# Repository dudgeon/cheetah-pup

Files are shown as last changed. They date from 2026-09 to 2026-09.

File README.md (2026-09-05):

# Cheetah Pup

An experimental, hobbyist-scale quadruped robot for reinforcement-learning research:
Mini-Cheetah-style 12-DOF body geometry and leg kinematics, built with Feetech
STS3215-class smart servos and much of the surrounding stack (power, sensors, training
approach) drawn from Hugging Face/Pollen Robotics' open-source **Open Duck Mini v2**
project.

**Status**: Phase 1 complete, Phase 2 CAD first pass done. The design is locked (candidate A ·
direct drive, size M — see [`docs/design/01-candidates.md`](docs/design/01-candidates.md) and
`docs/design/locked.json`), the MuJoCo model is validated
([`docs/design/02-sim-validation.md`](docs/design/02-sim-validation.md)), the RL environment is
built and smoke-tested ([`docs/design/03-rl-environment.md`](docs/design/03-rl-environment.md)),
and the build123d CAD of every printed part now feeds the simulator its masses, inertias and
meshes ([`docs/design/04-cad-detail.md`](docs/design/04-cad-detail.md)). Next: confirm the servo
interface on a real STS3215, the first cloud-GPU training run, and the second CAD pass.

**Start here**: [`docs/HANDOFF.md`](docs/HANDOFF.md) is the project plan — decisions made and
why, architecture, phased build sequence, budget, safety, and open questions.
[`docs/DESIGN_LOG.md`](docs/DESIGN_LOG.md) is the dated record of decisions and milestones.
[`docs/research-appendix.md`](docs/research-appendix.md) is the research backing the decisions.

## Repo layout

```
cheetah_pup/            Design library (SI units): servo + electronics data, parameters and
                        presets (incl. the locked design), 3-DOF leg kinematics, gait generation,
                        sizing analysis, MJCF generation, MuJoCo validation, page builders
cheetah_pup/rl/         MuJoCo Playground (MJX) environment, domain randomization, PPO runner
cad/                    build123d CAD: STS3215 model and interface conventions, printed parts in
                        their MuJoCo body frames, assembly + mass properties + STEP/STL export
cad/exports/            Generated: step/ and stl/ per part, mass_properties.json (read by the
                        MJCF generator), viewer_meshes.json (read by the DR-04 page builder)
sim/                    Generated models (cheetah_pup.xml, cheetah_pup_rl.xml) and validation
                        recordings; checkpoints are written to sim/checkpoints (ignored)
tests/                  pytest suite (design library, MJCF, RL environment)
docs/                   Plan, design log, research; docs/design/ holds each design review
docs/design/review/     DR-01 candidate review page (template + build)
docs/design/replay/     DR-02 sim playback page (template + build)
docs/design/cad/        DR-04 CAD review page with a WebGL viewer (template + build)
vendor/                 Git submodules: external reference repos (see vendor/README.md)
```

PCB design and firmware directories will be added as those build phases start (see
`docs/HANDOFF.md` §5).

## Working with the code

```
python -m venv .venv && .venv/bin/pip install -e ".[sim,rl,dev]"
.venv/bin/pytest tests/test_kinematics.py tests/test_analysis.py tests/test_mjcf.py   # fast
JAX_PLATFORMS=cpu .venv/bin/pytest tests/test_rl_env.py                               # ~2 min JIT
.venv/bin/python -m cheetah_pup.mjcf sim/cheetah_pup.xml            # model from the locked design
.venv/bin/python -m cheetah_pup.mjcf sim/cheetah_pup_rl.xml --rl    # training variant
.venv/bin/python -m cheetah_pup.validate sim/cheetah_pup.xml        # stand + gait recordings
.venv/bin/python -m cheetah_pup.build_replay                        # rebuild the DR-02 page
.venv/bin/python -m cheetah_pup.build_artifact                      # rebuild the DR-01 page
JAX_PLATFORMS=cpu .venv/bin/python -m cheetah_pup.rl.train --smoke  # PPO pipeline check
```

The CAD needs the `cad` extra (build123d pulls in OCP, so use a separate venv if the sim one
is precious):

```
python -m venv .venv-cad && .venv-cad/bin/pip install -e ".[cad]"
.venv-cad/bin/python -m cad.assembly                 # STEP/STL, mass_properties.json, viewer meshes
.venv/bin/python -m cheetah_pup.mjcf sim/cheetah_pup.xml && .venv/bin/python -m cheetah_pup.mjcf sim/cheetah_pup_rl.xml --rl
.venv/bin/python -m cheetah_pup.build_cad_review     # rebuild the DR-04 page
```

`python -m cheetah_pup.mjcf` uses the CAD inertias and meshes whenever `cad/exports` matches the
locked design; `--no-cad` writes the Phase 1 primitive model instead.

`cheetah_pup.design.PRESETS` holds the candidates; `cheetah_pup.analysis.metrics()` sizes any
`DesignParams`. The review page's JavaScript mirrors the same math and cross-checks itself
against the package's numbers at load.

## Getting the code

This repo uses git submodules for vendored reference material:

```
git clone --recurse-submodules <this-repo-url>
# or, if already cloned:
git submodule update --init --recursive
```

## License

This repo's own code is MIT licensed (see `LICENSE`) unless noted otherwise. Vendored
reference material under `vendor/` keeps its own upstream license — see
`vendor/README.md` for exact terms per repo, including a few that are reference-only
pending license clarification from their authors.

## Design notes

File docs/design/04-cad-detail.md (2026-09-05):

# DR-04 — CAD detail of the locked design (Phase 2, first pass)

**Review page**: DR-04 · CAD detail — https://claude.ai/code/artifact/6b9c8170-cae2-4a28-a494-7ba0548bcc4b (WebGL viewer with
gait playback and a joint sweep, part and body tables, hardware checklist). Rebuild with
`python -m cheetah_pup.build_cad_review` after `python -m cad.assembly`.

**Files**: `cad/` (build123d model), `cad/exports/step/*.step` (per part plus
`assembly_nominal_stance.step` and the servo), `cad/exports/stl/*.stl` (millimetres, each part in
its MuJoCo body frame), `cad/exports/mass_properties.json` (per-part and per-body mass, centre of
mass, inertia; servo and electronics placements), `cad/exports/viewer_meshes.json` (viewer data).

## What was built

A parametric build123d model of the locked design, `cheetah_pup.design.locked()`, with every
printed part modelled in the frame of the MuJoCo body that carries it, so the STL files drop into
the simulator without transforms and the per-body mass properties are the simulator's `<inertial>`
elements. The servo is modelled from Open Duck Mini v2's STS3215 case meshes (`cad/servo.py`).

| Part | Qty | Class · effective solid | Each | Purpose |
|---|---|---|---|---|
| Trunk tub | 1 | shell · 95 % | 169.0 g, 143.5 cm³ | Floor, walls to the split, abad servo cradles (windowed shelves, ribs), end-wall bores and M2 holes, battery rails, Pi standoffs, lid bosses |
| Trunk lid | 1 | shell · 95 % | 72.8 g | Split to the top, vent slots, lid screws, PCB bosses hanging from the underside |
| Abad bracket | 4 (each a distinct mirror) | plate · 85 % | 13.6 g | Bolts to the abad horn; carries the hip servo with its horn at the thigh plane (back plate, bar, servo plate with Ø21 bore, gusset) |
| Thigh | 4 (2 L, 2 R) | plate · 85 % | 24.5 g | 3.5 mm plate on the hip horn; knee servo cradle gear-end-down inboard of the plate; knee bore and mounting holes |
| Shank | 4 (2 L, 2 R) | beam · 75 % | 9.3 g | Pad on the knee horn disc; 14 mm-wide beam with a jog inboard so the foot lands 3.25 mm outboard of the knee plane |
| Foot | 4 | TPU · 100 % | 5.0 g | Ø20 sphere at the sim's contact point (placeholder shape) |

Printed total 451 g; robot total **1.391 kg** with 12 servos (660 g), battery (125 g), Pi 5
(65 g), PCB + IMU (30 g), and 60 g of wiring — 1.6 % under the parametric estimate the sizing
used (1.413 kg).

## Servo interface convention (from the measured case)

- Frame: origin on the shaft axis at the horn-seat plane; L along the case (+35.1 to −10.1 mm),
  W ±12.36, A along the shaft (+A toward the horn; case bottom at −32.6).
- Fixed part: a 3 mm plate on the top-face step (A ∈ [1.1, 4.1]), four M2 screws (Ø2.4 clearance)
  into the tapped holes at (L, W) = (8.3, ±10.25) and (29.0, ±10.25); a Ø21 bore in which the
  Ø20 horn disc (A ∈ [2.1, 5.05]) rides as a plain bearing, 0.95 mm proud of the plate.
- Moving part: bolts to the horn's four Ø2.5 holes on r = 7 plus the Ø3.2 centre, seating on the
  proud disc face.
- Pockets: 0.4 mm clearance around the case, including the Ø20 × 2.1 idler disc on the bottom.

## Packaging refinements made while modelling (kinematics unchanged)

| Parameter | Phase 1 | Phase 2 | Why |
|---|---|---|---|
| `abad_link` | 40 mm | **43 mm** | Room for the hip servo case (24.7 wide) plus the bracket's servo plate between the abad axis and the thigh plane |
| `abad_to_abad` | 70 mm | **74 mm** | Abad servo cases (35.7 tall) side by side in the tub with the centre rib |
| `hip_x_offset` | 15 mm | **18 mm** | End wall (3) + step (1.1) + horn disc + bracket back plate before the hip axis |
| `foot_y_offset` | — | **3.25 mm** | The shank sits on the knee horn disc outboard of the thigh plate; the beam jogs back inboard but the foot ends 3.25 mm outboard |
| Layout | Pi 5 and PCB on a top layer, Pi transverse | **Battery on the floor, Pi 5 above it in the centre bay; PCB + IMU hung from the lid over the front abad servos** | The centre bay between the servo cradles is the only 60 mm-tall volume; the PCB fits the 26 mm above the servo tops |

Shell width follows from the servo bay: `shell_width = abad_to_abad + 2 × (10.1 + 0.9 + wall)`
= 102 mm; shell length stays 144 mm.

## In the simulator

`cheetah_pup/mjcf.py` now defaults to the CAD model for the locked design: explicit `<inertial>`
per body from `mass_properties.json`, the STL meshes as visuals (`meshdir` relative to the XML),
servos placed by the recorded frames, feet at `y = ±foot_y_offset`. Collision stays primitive:
foot spheres in both variants; a shell box and leg capsules (hidden geom group 3) in the full
model only. `--no-cad` still generates the Phase 1 primitive model for any preset.

Re-validation on the CAD model (`sim/validation/`, DR-02 rebuilt): stands with 0.9 mm sag and
0.76° droop, knee hold 0.249 N·m; open-loop walk and trot both survive 6 s (walk 0.024 m/s,
trot 0.069 m/s, pitch ≤ 10°); the RL environment's four CPU tests pass on the new model.

## Known gaps and hardware checks

The review page lists what to confirm before printing. In short: the servo hole patterns and
horn fastener size are measured from a mesh, not a datasheet; the Ø21 bore clearance must be
tuned to the printer; joints are single-sided on the horn; hip pitch is limited to about ±60° by
the knee-servo case against the tub corner; battery, Pi cooler, and PCB envelopes are assumptions;
no wire clips, foot sockets, or fork supports are modelled yet. The tub is 169 g against the
143 g parametric shell estimate — acceptable, more windows possible.

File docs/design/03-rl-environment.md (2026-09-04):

# DR-03 — RL environment for the locked design

**Status**: built and smoke-tested on CPU; ready for a cloud-GPU training run.
Code: `cheetah_pup/rl/` (`base.py`, `joystick.py`, `randomize.py`, `train.py`, `constants.py`).
Model: `sim/cheetah_pup_rl.xml` from `python -m cheetah_pup.mjcf sim/cheetah_pup_rl.xml --rl`.
Tests: `tests/test_rl_env.py`. Stack: MuJoCo Playground (MJX) + Brax PPO, the same lineage as
Open Duck Mini's training; the environment mirrors Playground's Go1 joystick task (Apache-2.0),
which is the same 12-DOF abad/hip/knee quadruped layout.

## Task

Track a body-frame velocity command (vx, vy, yaw rate) on flat ground at 50 Hz control,
2 ms physics. Commands: |vx| ≤ 0.25 m/s, |vy| ≤ 0.10 m/s, |yaw| ≤ 1.0 rad/s, resampled at random
intervals with a chance of zeroing each component (stand still is part of the task).

## What the policy sees and does

| | |
|---|---|
| Observation (policy, 49) | gyro (3), gravity direction in the IMU frame (3), command (3), joint positions − standing pose (12), joint velocities × 0.05 (12), last action (12), foot contacts (4) — only what the real robot measures (BNO055 + servo encoders + foot switches). Noise added to each. |
| Observation (critic) | the above plus accelerometer, base linear/angular velocity, joint state without noise, actuator forces, foot velocities, air times, trunk height |
| Action (12) | offsets from the standing pose, ×0.3 rad; motor targets are slew-limited to the STS3215 firmware cap (5.29 rad/s) and clipped to the joint ranges before reaching the PD servos |
| Termination | trunk up-vector z < 0.3 (~73° tilt) or NaN |
| Episode | 1000 steps (20 s) |

## Rewards (per step, scaled by dt)

Tracking: lin-vel `1.5·exp(−|Δv|²/0.02)`, ang-vel `0.75·exp(−Δω²/0.2)`. Posture: orientation
−5, vertical velocity −0.5, roll/pitch rate −0.05, pose −/+0.3 toward the standing pose, soft joint
limits −1, stand-still −0.5 when the command is zero, termination −1. Effort: torques −0.002,
energy −0.01, action rate −0.01 (all ~10× the Go1 coefficients — our torques are ~10× smaller).
Feet: air time +0.2 (swing ≥ 0.1 s), clearance −1 toward a 30 mm swing height, slip −0.1.

## Domain randomization (per environment)

Floor friction U(0.5, 1.0); joint Coulomb friction ×U(0.8, 1.2); armature ×U(0.9, 1.1); trunk CoM
±10 mm; every body mass ×U(0.9, 1.1) plus ±0.1 kg on the trunk; joint zero offsets ±0.03 rad;
servo kp ×U(0.85, 1.15); torque limit ×U(0.85, 1.05) (battery sag). Pushes are implemented but off
by default. Backlash and the servo's rate-limited internal target come with BAM's actuator model
in the next step.

## Model variant differences from `sim/cheetah_pup.xml`

Feet-only collisions (shell and legs do not collide — Playground's convention for training speed;
falls are caught by the tilt termination), pyramidal friction cone, contact sensors on each foot,
the IMU frame sensor set, and a `home` keyframe alias. Masses, geometry, and the servo model are
identical.

## Running it

```
# CPU pipeline check (a few thousand steps, small networks; ~10 min mostly JIT)
JAX_PLATFORMS=cpu .venv/bin/python -m cheetah_pup.rl.train --smoke

# GPU run (cloud): install jax[cuda12] and mujoco-warp, then
.venv/bin/python -m cheetah_pup.rl.train --impl warp --num-timesteps 100000000 --num-envs 4096
```

Playground's Go1 PPO hyperparameters are the starting point (policy 512-256-128, value the same,
observation normalization on). Expect a first walking policy within tens of millions of steps —
Microduck reports 1–2 hours on one GPU at 4096 environments for a comparable task.

## Smoke test result (CPU, 2026-09-04)

`--smoke`: 8 environments, 100-step episodes, 64-64 networks, 2,048 requested timesteps → 5,120
executed (Brax rounds up to whole batches), 133 s wall time of which nearly all is JIT compile.
Evaluation with the barely-trained policy: episode reward 0.78, average episode length 99.7 of
100 (the robot mostly stays upright for 2 s from the standing pose), every reward term finite and
of the expected sign (tracking +34.8/+20.0, pose +27.5, orientation −8.2, energy −16.2, torques
−3.4, action rate −6.5, feet air time +0.35). Checkpoint `sim/checkpoints/smoke_params` (87 KB)
saved with `brax.io.model`. This proves environment, randomization, PPO, evaluation, and
checkpointing run together; it says nothing about walking quality — that needs the GPU run.

One compatibility fix was needed: Brax 0.14.2 calls `jax.device_put_replicated`, removed in
JAX 0.10; `cheetah_pup/rl/compat.py` restores it with the documented replacement.

## Next steps

1. Cloud-GPU training run; evaluate with `sim/cheetah_pup.xml` (full collisions) and in the DR-02
   playback page (a policy-driven recording is one function away in `validate.py`).
2. Actuator realism: BAM's MuJoCo actuator (rate-limited target, extended friction, backlash).
3. ONNX export of the policy MLP for the Raspberry Pi runtime (Phase 4).

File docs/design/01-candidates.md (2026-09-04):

# DR-01 — Leg architecture & proportion candidates

**Status**: awaiting the owner's selection. Review page: https://claude.ai/code/artifact/6b9c92f0-98d5-4cf1-928c-98a28d699ba4
(source: `docs/design/review/template.html`, built by `python -m cheetah_pup.build_artifact`).
Date: 2026-09-04. Analysis code: `cheetah_pup/` (tests in `tests/`).

## What is being decided

All candidates share the Mini Cheetah kinematics fixed in `docs/HANDOFF.md` §3: four legs, each with
abduction/adduction (axis along x, through the hip-pitch axis), hip pitch, and knee pitch, serial 2R
leg, knees pointing backward by default. What differs is **where the knee servo lives and how it
drives the shank** — which changes mass distribution, hip width, build complexity, and how much the
sim has to model beyond the servo itself.

| | **A · Direct drive** | **B · Coaxial hip + belt knee** | **C · Coaxial hip + pushrod knee** |
|---|---|---|---|
| Knee servo location | at the knee, inside the thigh | at the hip, coaxial with the hip servo, outboard of the thigh | same as B |
| Knee transmission | none (horn drives the shank) | GT2 belt, 20T→25T (1.25:1) | printed 4-bar pushrod (~1.2:1 average) |
| Thigh | housing around a 55 g servo | slim printed link with a belt cavity | slim printed link |
| Overall width (size M) | **182 mm** | 253 mm | 253 mm |
| Mass (size M) | 1.41 kg | 1.46 kg | 1.45 kg |
| Knee servo, trot peak | 0.77 N·m (40 % of stall) | 0.65 N·m (34 %) | 0.67 N·m (35 %) |
| Abad / hip, trot peak | 0.52 / 0.31 N·m | 0.54 / 0.32 N·m | 0.53 / 0.32 N·m |
| Peak servo speed, 1.4 Hz trot | 76 % of cap | 94 % of cap | 91 % of cap |
| Electronics fit | yes | yes | yes |
| Sim-to-real modeling | servo only (BAM covers it) | servo + belt compliance/stretch | servo + variable ratio + pin play |

Baseline geometry (size M): thigh 90, shank 85, abad link 40, hips 180 apart (fore-aft), abad axes
70 apart, shell 148 × 62 mm, hip height 120 mm (nominal hip −45°, knee 93° — Mini Cheetah stands at
−46°/92°). Sizes S/L scale the legs by 0.85/1.15.

## Findings that shaped the candidates

1. **The STS3215's speed cap, not its torque, is the binding constraint.** BAM's identification puts
   the firmware's target-rate limit at 5.29 rad/s (≈50 rpm). A 1.4 Hz trot with a 60 mm step and
   25 mm swing needs ~4 rad/s at the knee in direct drive. Any knee reduction multiplies servo speed by
   the same ratio: 1.5:1 (the first belt guess) exceeded the cap; 1.25:1 sits at 94 %. Practical
   trot frequency with these servos is ~1.2–1.5 Hz, i.e. 0.15–0.2 m/s. This is the "confident walker,
   not sprinting cheetah" trade-off from the decision log, now with a number on it.
2. **Direct drive does not need a reduction.** Knee torque at the trot peak (two legs, 1.5× dynamic
   factor, foot swept over the step) is ~0.77 N·m against a 1.91 N·m stall — 40 %, inside the 60 %
   peak allowance, and 12 % when standing on four legs. The belt's torque margin is a nice-to-have
   bought with speed.
3. **The Raspberry Pi 5 mounts transversely.** The shell is ~93 mm wide inside (set by the abad
   servos), so the Pi's 85 mm side fits across the body and it occupies only 56 mm of length. That
   freed ~40 mm and is why the body can stay near Mini Cheetah's length ratio (2.0× thigh vs 1.82).
4. **Abad torque is the second-largest load** (~0.53 N·m at trot peak) because the foot stands
   ~40 mm outboard of the abad axis — the price of a 36 mm-long servo in the hip cluster. Keep the
   abad link as short as the hip servo allows; the slider exposes it.
5. **Coaxial hip clusters cost +70 mm of width.** Two 36 mm servos side by side on the hip axis with
   the thigh between them make B and C nearly as wide as they are long (253 vs 260 mm); A's hip servo
   tucks inboard of the thigh plane.
6. **Hip servo clearance**: with the hip-pitch servo case pointing up from the hip axis, the hip axis
   needs to sit ≥ 16 mm beyond the shell end wall (`hip_x_offset`), or the case collides with the
   body. Baseline set to 16 mm.

## Recommendation

**A · Direct drive.** It is the lowest-risk path to a working RL robot and the best fit for the
"reuse the Hugging Face stack" decision: Open Duck Mini's joints are directly servo-driven, so its BAM
actuator identification, backlash modeling, and sim-to-real pipeline apply without adding a
transmission model. Torque margin is adequate at size M and speed margin is the best of the three.
Its costs — a heavier lower thigh and higher leg inertia — are real but small at this scale (swing
accelerations need ~0.04 N·m at the hip).

**B** is the choice if the owner values the Mini Cheetah look and low leg inertia and accepts the
width, the belt hardware, and belt stretch in the sim. A 1:1 belt (20T→20T) keeps A's torque/speed
numbers while still moving the servo mass to the hip — the ratio slider on the review page shows
that trade directly. **C** is least favored: the linkage bounds the knee range (~100°) and its
variable ratio is the hardest of the three to mirror in simulation.

## How to review and record a decision

The review page draws all three candidates at one scale (1.5 px per mm in every view) with the
servos at their measured size, the electronics volumes in the body, and the legs animated through
stand/crouch, walk, trot, pace, bound (range-of-motion demo), and lateral sway. Sliders change the
proportions and gait; the sizing panels and the "Current proposal" summary update live. **Save
decision** stores the candidate, slider values, tags, and comments to the page's data store
(`feedback/current`, plus a `reviews` log); Claude reads it back with the artifact tools. If the
store is unavailable, **Copy summary** and paste it into chat.

## After selection

1. Add a `LOCKED` preset to `cheetah_pup/design.py` from the saved decision (`docs/design/locked.json`).
2. Generate the MJCF from it: primitive collision geometry, component masses, STS3215 actuator model
   from BAM's parameters (position actuator with the identified kp/velocity cap, friction, armature).
3. Validate standing and IK-driven gait playback in MuJoCo; then build the RL environment.

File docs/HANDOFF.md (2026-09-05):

# Cheetah Pup — Handoff Document

**Status** (2026-09-04): Phase 1 complete. Research done, architecture decided, design library
built and tested, DR-01 candidates reviewed, **design locked (A · M)**, MuJoCo model generated and
validated open-loop (DR-02), and the **RL environment built and smoke-tested on CPU (DR-03)**.
**Next: the first cloud-GPU training run**, then Phase 2 CAD in parallel.

## 0. Progress

| Phase | State | Where |
|---|---|---|
| 0 · Repo & tooling | done | this repo; `vendor/README.md` |
| 1 · Kinematic validation | **done** — design locked; sim model validated (DR-02, re-run on the CAD model 2026-09-05); RL environment built (DR-03) | `docs/design/locked.json`, `cheetah_pup/mjcf.py`, `sim/cheetah_pup.xml`, `docs/design/02-sim-validation.md`, `docs/design/03-rl-environment.md`, `cheetah_pup/rl/`; DR-01 review https://claude.ai/code/artifact/6b9c92f0-98d5-4cf1-928c-98a28d699ba4; DR-02 playback https://claude.ai/code/artifact/2db54b1d-2707-4034-895f-95bec2b86281 |
| 2 · Mechanical CAD | **first pass done** (2026-09-05) — build123d model of every printed part with the measured STS3215 interface, STEP/STL exported, per-body mass properties feeding the sim (DR-04). Next: confirm the servo hole patterns on a real servo, then foot sockets, wire routing, fork supports, and the owner's Fusion 360 pass | `cad/`, `cad/exports/`, `docs/design/04-cad-detail.md`; DR-04 CAD review https://claude.ai/code/artifact/6b9c8170-cae2-4a28-a494-7ba0548bcc4b |
| 3 · Electrical / PCB | not started; volumes and power rails fixed in the design library | `cheetah_pup/electronics.py` |
| 4 · Firmware | not started | — |
| 5 · RL training | environment ready (`cheetah_pup/rl/`) and passing on the CAD-derived model; first GPU run pending; BAM actuator model to add | `docs/design/03-rl-environment.md`, `vendor/bam` |
| 6 · Bring-up | not started | — |

Keep `docs/DESIGN_LOG.md` current: one dated entry per decision or milestone.

**Purpose of this document**: everything needed to pick up this project cold and start the
detailed spec-and-build phase, without re-deriving decisions already made or re-running research
already done. If you're Fable 5.1 (or any future session) starting fresh: read this document in
full before writing any code, then start at [§8 Immediate next steps](#8-immediate-next-steps).

---

## 1. Project vision

An experimental quadruped robot for reinforcement-learning research:

- **Body geometry and leg kinematics** based on MIT's Mini Cheetah — full 12-DOF topology
  (hip abduction/adduction + hip pitch + knee pitch, ×4 legs), serial 2R leg chain per the real
  robot (not a parallel/5-bar linkage).
- **Actuators and much of the surrounding stack** based on Hugging Face/Pollen Robotics'
  **Open Duck Mini v2** — Feetech STS3215-class serial-bus smart servos, similar power
  architecture, similar sensor stack, and a training approach descended from the same lineage
  (MuJoCo-based RL, with Microduck's newer BAM-based actuator-identification approach folded in).
- A **custom PCB** for motor-bus, power, and sensor breakout (Open Duck Mini itself uses only an
  off-the-shelf Waveshare adapter — there is no existing open custom board for this actuator
  class doing exactly what we need, which is genuinely new work, not just a port).
- Scaled for a **hobbyist build**: FDM-printed structure, outsourced PCB assembly, Raspberry-Pi-class
  compute, cloud-GPU training.

This deliberately does **not** replicate the real Mini Cheetah's actuator technology (custom
quasi-direct-drive BLDC + FOC motor control). See §3 for why, and what that trade-off costs us.

---

## 2. How to use this document

- **§3** is the decision log — what was decided, why, and what alternatives were rejected. Don't
  relitigate these without a good reason; if you find one, update this log rather than silently
  diverging.
- **§4–§7** is the actual plan: architecture, phased build sequence, BOM/budget, safety.
- **§8** is where to start.
- **§9** is what's deliberately left open for you to resolve, with pointers to how.
- Full research backing every claim below lives in `docs/research-appendix.md` — this document
  states conclusions; that one shows the work.
- Reference repos are vendored as git submodules under `vendor/` — see `vendor/README.md` for
  what's there, exact licenses, and usage rules (a few are reference-only pending license
  clarification — don't copy code from those verbatim).

---

## 3. Decision log

These were made through direct interview with the project owner (dudgeon) on 2026-09-04, after
the research pass. Each is a real trade-off, not an arbitrary choice — the "why" matters if you
ever need to revisit one.

| Decision | Chosen | Alternatives considered | Why |
|---|---|---|---|
| **Actuators** | Duck-style smart servos (Feetech STS3215-class, serial bus, position-controlled) | True QDD BLDC (MIT-Cheetah/Solo12-style); hybrid | Matches the literal ask ("same actuators as the HF duck project"), reuses the most existing hardware/software, and is dramatically more tractable for a hobbyist build — no custom FOC motor-controller firmware needed. **Trade-off, stated explicitly and accepted**: not backdrivable, not true torque control. This robot will be a confident, capable *walker*, not a bounding/jumping *runner*. If dynamic gaits become a real goal later, that's a distinct future initiative (see §9), not a retrofit. |
| **Leg DOF** | Full 12-DOF (ab/ad + hip + knee ×4), matching real Mini Cheetah | Simplified 8-DOF (Solo8-style, sagittal only) | Explicitly requested as most faithful to "MIT Cheetah kinematics"; enables turning in place and lateral push recovery that an 8-DOF design can't do well. Costs 4 more servo channels/wiring runs than the simpler option. |
| **Fabrication access** | 3D printer (FDM) at home; PCB assembly outsourced (JLCPCB/PCBWay-style) | Hand-soldering fine-pitch SMD | **PCB design must use assembly-service-friendly footprints** (no 01005/BGA-if-avoidable, standard connectors) since hand-soldering fine-pitch SMD is not a confirmed skill. Structure/legs are FDM-printable — matches nearly every reference project surveyed. |
| **Training compute** | Cloud GPU credits, macOS as the dev/orchestration machine; local GPU explicitly deferred | Local NVIDIA GPU now; CPU-only | Not compute-constrained for the training stack choice — both MuJoCo Playground and the GPU-hungrier mjlab are viable. A **low-priority backlog item** (see §9.5) tracks revisiting local/hybrid GPU augmentation if cloud spend gets high; NVIDIA's brand-new "PAIR" project (announced 2026-09-03) was checked and does **not** help here — it's LAN-only inference pooling, not cloud training offload. |
| **CAD toolchain** | Code-first: **build123d** (or CadQuery as fallback) for parametric geometry + hand-authored **MJCF** for the early kinematics validation | Onshape | **Onshape is confirmed unreachable from this sandbox** (network egress test returned 403 on the CONNECT tunnel — the environment's proxy blocks it, same pattern the research agents hit on most non-GitHub domains). Since the owner wants Claude/Fable operating end-to-end from a Claude Code cloud instance without needing GUI CAD access, and wants STEP files that import cleanly into **Fusion 360** for their own later refinement pass, a scriptable Python CAD library is the only toolchain that satisfies both constraints. **Verify current pip-installability of build123d at the start of Phase 2** — if it has issues, CadQuery is the established fallback; both export STEP. |
| **Milestone sequencing** | Validate kinematics/topology in a *primitive-geometry* MuJoCo sim **before** investing in real CAD or manufacturability | Design real CAD first | The owner's own framing, adopted as-is: "a relatively early milestone should be validating a simple version of the design and kinematics in the RL environment to see if the basic project will work... and we will later refine, think about manufacturability." This is Phase 1 below, and it deliberately needs no CAD-derived meshes — simple boxes/capsules are enough to test whether the topology, proportions, and torque budget are sound. |
| **Experience / division of labor** | Claude/Fable drives ~95% of CAD, 100% of PCB/firmware/RL design; owner has CAD/DFM experience (not advanced linkages) and will do manufacturability refinement in Fusion 360 later | — | Stated directly. Electronics, embedded firmware, and ML/RL were **not** selected as areas of existing hands-on experience — treat those as fully Claude/Fable-driven too, not just CAD. The plan below is written assuming heavy autonomous execution with clear checkpoints for physical assembly (the one thing that must be done by human hands) and design review. |
| **Budget** | $600–$1,500 (excluding the 3D printer already owned) | — | See §6 for a rough BOM sanity check against this. |
| **License / distribution intent** | Personal project, **likely to open-source publicly** | Pure personal use; commercial | Drives §9.2 (unlicensed-repo caveats) and the recommended MIT license on this repo's own code (added — see root `LICENSE`). Since we're not depending on Microduck's CC BY-SA-NC assets at all (different hardware base), that restriction doesn't currently constrain us — but don't pull anything from `pollen-robotics/microduck_rl`'s asset files later without re-checking. |
| **Servo data source** (Phase 1) | STS3215 geometry measured from Open Duck Mini v2's case meshes; electrical/friction model from BAM's identified 7.4 V parameters | datasheet values from memory | Measured meshes and an identified model beat a remembered datasheet; both are vendored (`vendor/open_duck_mini`, `vendor/bam`) and encoded in `cheetah_pup/servo.py`. Design margins use the *datasheet* stall (1.91 N·m), not BAM's more optimistic implied stall. |
| **Sizing design point** (Phase 1) | Trot at 1.4 Hz, 60 mm step, 25 mm swing; loads = ¼ weight standing (≤ 25 % of stall) and ½ weight × 1.5 dynamic at trot peak (≤ 60 % of stall) | 1.6 Hz trot | 1.6 Hz pushed the knee past the STS3215's 5.29 rad/s cap even in direct drive. The cap, not torque, limits gait speed with these servos — accepted as the walker trade-off. |
| **Electronics layout** (Phase 1) | Two layers: abad servos + battery low, Pi 5 (transverse) + PCB high | Pi lengthwise | Transverse Pi saves ~40 mm of body length and keeps hip-to-hip near Mini Cheetah's 1.82× thigh ratio (2.0×). |
| **Knee-drive architecture & size** (locked 2026-09-04) | **A · direct drive, size M**, knees back, baseline proportions and gait — `cheetah_pup.design.locked()`, `docs/design/locked.json` | B coaxial + belt; C coaxial + pushrod; sizes S/L | Owner accepted the DR-01 defaults. A is the lowest-risk path and the best fit for reusing Open Duck Mini's directly-driven-joint sim-to-real pipeline; 40 % of stall at trot peak, 76 % of the speed cap, narrowest hips. |
| **Sim actuator model** (Phase 1) | MuJoCo `general` PD from BAM's electrical model (kp 18.8 N·m/rad, kd 0.56 N·m·s/rad), clamped at the datasheet stall 1.91 N·m; joint armature 0.026 kg·m², Coulomb 0.05 N·m | BAM's implied 3.4 N·m stall; BAM's full stateful model | Conservative clamp for viability; `--bam` flag generates the optimistic variant. The RL environment should move to BAM's MuJoCo integration (rate-limited target, extended friction) for the real training runs. |
| **Servo interface convention** (Phase 2, 2026-09-05) | Fixed part = 3 mm plate on the STS3215's top-face step, 4 × M2 into the case's tapped holes; Ø20 horn disc rides in a Ø21 printed bore as a plain bearing; moving part bolts to the horn's r = 7 pattern. Single-sided joints | Fork (idler-side) support on every joint; metal bearings | Derived from the measured case geometry (`cad/servo.py`); the simplest joint that uses the servo's own horn as the bearing, as Open Duck does. Fork supports are drawn as an upgrade path in the thigh cradle if horn play shows up. **Hole positions and horn screw size must be confirmed on a real servo** (§9.10). |
| **Phase 2 packaging refinements** (2026-09-05) | abad link 43 mm (was 40), abad axes 74 apart (was 70), hip x-offset 18 (was 15), feet 3.25 mm outboard of the knee plane; battery on the floor, Pi 5 above it in the centre bay, PCB + IMU hung from the lid over the front abad servos; shell 144 × 102 × 62 | Keep Phase 1 numbers and squeeze the parts | Each change is the minimum the real servo cases and interfaces need; leg lengths, hip spacing, stance and gait are unchanged, so the DR-01 sizing still holds (re-validated in sim). `docs/design/04-cad-detail.md` has the table. |
| **Sim fidelity source** (2026-09-05) | `mjcf.py` defaults to the CAD for the locked design: explicit `<inertial>` per body from `cad/exports/mass_properties.json`, STL meshes as visuals, feet spheres (plus hidden shell box and leg capsules in the full model) for collision | Mesh convex hulls for collision; keep the primitive model | Primitive collisions keep the RL model fast and match Playground's quadruped scenes; the CAD gives the masses and inertias the policy actually needs to be right. `--no-cad` keeps the Phase 1 model for the unlocked presets. Total 1.391 kg vs the 1.413 kg parametric estimate. |

---

## 4. Architecture overview

### 4.1 Mechanical
12-DOF quadruped, Mini-Cheetah-proportioned (long body relative to leg length, legs tucked
under the body rather than sprawled like a hobby "SpotMicro"-style bot). Actuators mounted at
the hip where possible (co-axial stacking, like Mini Cheetah/Open Duck Mini) to keep leg swing
mass — and thus reflected inertia the servo has to fight — low, even though we're not chasing
true QDD dynamics. Final scale/mass to be derived from servo torque budget during Phase 1 (see
§5), not fixed in advance — expect something in the rough neighborhood of Open Duck Mini's
footprint (that robot closes the loop on "how big can a 7.4V STS3215-driven robot be"), adapted
for quadruped proportions.

### 4.2 Electrical
- **Servos**: 12–14× Feetech STS3215-class, 7.4V, on a shared serial bus (final servo count and
  whether any joints need a higher-torque variant depends on Phase 1 torque analysis).
- **Custom PCB** (the "motor and sensor breakout" from the original brief): distributes bus +
  power to per-leg connectors (4 runs, not one long daisy chain through everything — more
  robust, easier to service than the stock Waveshare adapter's single chain), regulates 2S
  Li-ion (~7.4V, matches servo voltage directly with no separate boost/buck needed for the
  servo rail) down to 5V for compute and 3.3V for sensors, breaks out I2C for the IMU and room
  for future sensors (ToF, foot contact), includes battery voltage/current sensing, a fuse +
  reverse-polarity protection, and a **software+hardware E-stop** (MOSFET-switched servo power
  rail, killable independently of the Pi) — see §7 Safety.
- **Power**: 2S 18650 Li-ion pack + 2S BMS, mirroring Open Duck Mini v2 exactly (their choice
  already validates this voltage matches STS3215 servos directly).
- **Compute**: Raspberry Pi 5 (more headroom than Open Duck Mini's Pi Zero 2W — Pupper v3 made
  the same call for similar reasons: room for a camera and future sensor/ML work without being
  compute-starved). Pi Zero 2W remains a fallback if size/weight pressure shows up in Phase 1/2.
- **Sensors**: Bosch BNO055 9-DOF IMU at minimum (matches Open Duck Mini's choice, and BAM
  already models this class of setup); camera and/or foot-contact sensing as stretch additions
  once core locomotion works.

### 4.3 Software / training
- **Phase 1 (kinematics validation)**: quickest-to-stand-up MuJoCo setup (plain MuJoCo or MuJoCo
  Playground) on a hand-authored primitive-geometry MJCF. Goal is a yes/no answer on topology
  and rough torque budget, not a polished policy.
- **Phase 5 (production training)**: given cloud GPU is available (not the hobbyist
  hardware-constrained case Playground is optimized for), lean toward **mjlab** — it's the stack
  Microduck itself actually runs today, giving the closest "same stack as the HF project" match,
  and it comes with `rsl_rl` + BAM integration already proven together. Keep MuJoCo Playground as
  the fallback if mjlab setup friction becomes a blocker — both are documented in
  `docs/research-appendix.md` §4.
- **Actuator realism**: `vendor/bam` already ships identified friction parameters for Feetech
  STS3215 @ 7.4V — start from those, then re-identify against our actual robot once hardware
  exists (BAM's pipeline is built for exactly this).
- **Reference motion / reward shaping**: cannot reuse Open Duck Mini's bipedal reference-motion
  generator directly (quadruped trot ≠ bipedal balance), but the *approach* (procedural
  generation via IK rather than mocap, using the Placo library) is worth adapting — quadruped
  trot/walk cycles are kinematically simpler than bipedal balance, so this should be less work,
  not more.
- **Deployment**: ONNX export, ~50Hz on-robot policy execution — matches both Open Duck Mini and
  Microduck's control rate, a reasonable default rather than something to re-derive.

---

## 5. Phased build plan

Each phase lists its goal, key tasks, and what "done" looks like. Phases are sequential but not
rigidly gated — e.g. PCB design (Phase 3) can start once Phase 1 gives rough current/voltage
requirements, without waiting for Phase 2's CAD to be finished.

### Phase 0 — Repo & tooling scaffolding ✅ *done this session*
Research, submodules, this document, initial repo structure, MIT license.

### Phase 1 — Kinematic/topology validation in sim
**Goal**: answer "does the basic idea work" as cheaply as possible, before investing in real CAD.
- Hand-author (or script) a primitive-geometry MJCF: 12-DOF topology, reasonable guessed link
  lengths/masses based on Mini Cheetah's proportions scaled to a target mass, box/capsule
  collision geometry — no real meshes needed yet.
- Stand up a MuJoCo training loop (plain MuJoCo or MuJoCo Playground — whichever is faster to get
  running) and get a policy learning to stand, then walk, even crudely.
- Pull in `vendor/bam`'s STS3215 @ 7.4V parameters early — cheap to include, makes this
  validation more realistic than idealized actuators would.
- Check peak/continuous torque demand from the trained policy against STS3215's ~19 kg·cm rating
  at the chosen leg geometry — this is what actually determines final size/mass, not the other
  way around.
- **Done when**: a policy reliably stands and achieves basic forward locomotion in sim, within
  the chosen servos' torque/speed envelope. If it can't, that's a real finding — iterate on
  proportions/mass before moving on, not after building hardware.

### Phase 2 — Mechanical CAD & manufacturability
- Translate the validated topology into parametric CAD (build123d, scripted), incorporating real
  STS3215 mounting geometry/servo horns, bearing points, wire routing, battery/compute/PCB
  volume, and DFM for FDM printing (wall thickness, overhangs, print orientation, split lines for
  bed size).
- Export STEP; hand off to the project owner for a Fusion 360 refinement pass (aesthetics,
  manufacturability polish, anything requiring their DFM judgment).
- Re-derive MJCF collision geometry and mass properties from the real CAD model; re-run Phase 1's
  validation as a sim-to-sim consistency check before moving on.
- **Status 2026-09-05**: first pass done — `cad/` (build123d: servo model, parts in MuJoCo body
  frames, assembly with mass properties), `cad/exports/` (STEP, STL, `mass_properties.json`),
  MJCF regenerated from the CAD and re-validated (DR-02), DR-04 review page. Not yet modelled:
  foot sockets, wire clips/strain reliefs, fork supports, print-in-place features; the servo
  hole patterns are measured from a mesh and need a hardware check (§9.10) before the first print.

### Phase 3 — Electrical: power, sensors, custom PCB
- Schematic + layout (KiCad) for the motor-bus/power/sensor breakout board described in §4.2.
- Design for outsourced assembly: standard footprints, no hand-soldering-only parts.
- Reference `vendor/odri_actuator_hardware` for board architecture patterns (connector choices,
  power distribution) even though the underlying actuator circuit is different.
- Order a small-batch assembled run.

### Phase 4 — Firmware & on-robot integration
- Raspberry Pi 5 control loop: sensor reads (IMU, later foot contact), servo bus driver, ONNX
  policy execution at ~50Hz, safety/torque-limiting, telemetry/logging.
- Architecture informed by reading `vendor/open_duck_mini_runtime` — **reimplement
  independently**, don't copy verbatim (see license caveat in §9.2).

### Phase 5 — Full RL training with real actuator ID + domain randomization
- Re-run BAM identification against the actual assembled robot's servos (starting from the
  vendored STS3215 @ 7.4V parameters).
- Build the full domain-randomization suite (friction, mass, latency, battery sag, backlash) and
  quadruped-specific reward shaping (trot symmetry, foot clearance, etc.).
- Train in mjlab (or MuJoCo Playground — see §4.3) on cloud GPU; export ONNX.

### Phase 6 — Bring-up & iteration
- Assemble, flash, deploy. Tethered/propped-up testing first, progressive gait validation (stand
  → weight shift → step → walk → trot). Diagnose and close the sim-to-real gap.

### Phase 7 — Stretch goals (not in current scope)
Higher-speed gaits, vision-based navigation/obstacle avoidance, additional sensing. **True
dynamic gaits (bounding, jumping) are explicitly out of scope** under the current smart-servo
actuator decision — revisiting that would mean reopening §3's actuator decision, not extending
this phase.

---

## 6. Rough BOM / budget sanity check

Order-of-magnitude only — final part selection happens in Phases 1–3. Excludes the 3D printer
(already owned).

| Category | Rough estimate | Basis |
|---|---|---|
| 12× Feetech STS3215-class servos | $120–160 | Open Duck Mini's own BOM (~$10–13/unit in this quantity) |
| Custom PCB, small-batch assembled | $50–150 | Outsourced assembly, complexity-dependent |
| Raspberry Pi 5 | $60–80 | |
| IMU + misc sensors | $20–40 | BNO055-class + headroom |
| Battery (2S Li-ion) + BMS | $30–50 | Matches Open Duck Mini's power architecture |
| 3D printing filament | $30–50 | Printer already owned |
| Fasteners, bearings, wiring, connectors | $50–100 | |
| **Rough total** | **~$400–650** | |

This lands comfortably under the $600–1,500 budget, leaving real margin for design iteration,
spares, and mistakes (expect some — first-time servo/PCB bring-up rarely goes perfectly). Not a
reason to gold-plate the spec; a reason not to panic about a second PCB revision or a couple of
replacement servos.

---

## 7. Safety considerations

Not optional, even for a small hobbyist robot — 12+ torque-capable servos under an RL policy
that hasn't been validated on hardware yet is a real pinch/impact hazard, and Li-ion packs have
real failure modes.

- **E-stop**: hardware kill switch on the servo power rail (MOSFET, switchable independently of
  Pi software state), plus a software-level "disable torque" path — both should work even if the
  other has failed or the policy is misbehaving.
- **Bring-up protocol**: first policy deployments tethered or with the robot propped up
  off the ground (legs can move freely but can't launch the body), before any free-standing test.
- **Battery**: 2S Li-ion needs a proper BMS (already in the power architecture, §4.2) — charge
  only with a balance charger, never leave charging unattended, standard Li-ion fire-safety
  practice (charge on a non-flammable surface, away from combustibles).
- **Torque limiting**: cap servo torque/speed in firmware below hardware maximums during initial
  bring-up and testing, raise only once behavior is trusted.

---

## 8. Immediate next steps

1. **First GPU training run** (owner's cloud credits): `pip install -e ".[sim,rl]"` plus
   `jax[cuda12]` and `mujoco-warp` on the instance, then
   `python -m cheetah_pup.rl.train --impl warp --num-timesteps 100000000 --num-envs 4096`.
   Evaluate the checkpoint in `sim/cheetah_pup.xml` (full collisions) and record a policy-driven
   run for the DR-02 playback page. Tune reward scales from what the first policy does wrong.
2. **Actuator realism**: swap the PD approximation for BAM's MuJoCo actuator model
   (`vendor/bam`, native STS3215 @ 7.4 V params: rate-limited target, extended friction, backlash)
   before the runs that will be deployed.
3. **Policy export**: ONNX of the policy MLP + observation normalization for the Raspberry Pi
   runtime (Phase 4); Open Duck's `export_onnx.py` shows the Brax-params-to-ONNX path.
4. **Phase 2, second pass**: (a) put a real STS3215 on the bench and confirm the top-face hole
   pattern, horn screw size, idler disc, and the Ø21 bore fit with a test print of one thigh;
   (b) model the foot socket, wire routes with clips, and the fork support option; (c) re-export
   and hand the STEP files to the owner for the Fusion 360 pass. Every CAD change re-runs
   `python -m cad.assembly` → `python -m cheetah_pup.mjcf` (both variants) → validation → DR-02/DR-04.
5. Keep this document, `docs/DESIGN_LOG.md`, and the task list current as decisions get made.

---

## 9. Open questions / deferred decisions

Things deliberately left unresolved rather than guessed at — resolve these as they become
relevant, pulling the owner in only where marked.

### 9.1 Final servo count, and whether any joint needs extra torque — resolved 2026-09-04
Twelve identical STS3215s: DR-01's sizing puts the knee at 40 % of stall at the trot peak, the
abad at 29 %, the hip at 16 %; speed (the 5.29 rad/s cap), not torque, is the binding limit.
Revisit only if the first policy saturates a joint in the CAD-mass model.

### 9.2 Licensing on the three unlicensed Open Duck repos
`open_duck_mini_runtime`, `open_duck_playground`, and `open_duck_reference_motion_generator` have
no LICENSE file (confirmed by direct inspection of the vendored clones, not just secondhand
research) — legally all-rights-reserved by default despite the project's "open source" framing.
Given the intent to eventually open-source this repo (§3), **reach out to the author (Discord:
`discord.gg/UtJZsgfQGe`) to request explicit licensing terms** before our own repo ships any code
that was directly copied/adapted from those three repos. Until then, treat them as
architecture/approach references only (already reflected in `vendor/README.md`'s usage rules).
**Needs the owner's input** on whether/when to make that outreach.

### 9.3 CAD toolchain — resolved 2026-09-04
build123d 0.11.1 installs and runs in this sandbox (`~/venv-cad`); STEP export is available for the
owner's Fusion 360 pass. CadQuery remains the fallback if a later version breaks.

### 9.4 Training stack: mjlab vs. MuJoCo Playground — partly resolved
MuJoCo 3.12 installs and steps in this sandbox (`~/venv-sim`), so the Phase 1 model validation runs
here on CPU. The choice between mjlab and MuJoCo Playground for GPU training is still open and
belongs to Phase 5; §4.3 leans toward mjlab given cloud GPU access, with Playground as the fallback
if setup friction is high.

### 9.5 [Low priority] Local/hybrid GPU augmentation for training
Tracked as task #9 in this session's task list. Cloud-GPU-first is the current plan; revisit only
if cloud spend becomes a real cost concern. NVIDIA PAIR (checked, §5 of the research appendix)
does not help — it's local-network inference pooling, not cloud training offload. If this becomes
relevant, look at DGX Cloud / DGX Cloud Lepton next (unconfirmed relevance — wasn't deeply
researched, flagged only as the more plausible next thing to check).

### 9.6 Appendages / behaviors beyond core locomotion
No decision was made on whether this robot gets a head, tail, or any non-locomotion
expressiveness (Open Duck Mini has a 4-DOF neck for character; Mini Cheetah has none). Not
mentioned in the original brief — treat as out of scope unless the owner raises it.

### 9.7 Target size/mass — resolved 2026-09-04
Size M locked (thigh 90 mm, 1.41 kg modeled, 120 mm hip height). S/L remain available as presets
if Phase 2 CAD or bring-up argues for a change.

### 9.8 Knee-drive architecture — resolved 2026-09-04
A · direct drive locked (owner accepted the DR-01 defaults). B/C presets stay in the library for
reference.

### 9.9 Open-loop speed loss — carry into the RL environment
Open-loop trot reaches a third of its commanded speed: the trunk pitches under the rear legs and
the front feet float most of the cycle (servo tracking itself is fine, 2–3° mean error). A crude
leveling term recovers speed but oscillates. Both behaviors are what the policy must learn around;
keep torque saturation and BAM's rate-limited target in the training model so the policy does not
learn an unrealistically fast robot, and give it the IMU (orientation + rates) in the observation.

### 9.10 Servo interface measured from meshes — confirm on hardware
`cad/servo.py` encodes the STS3215 case, horn, idler disc, and the top-face M2 hole pattern
((8.3, ±10.25) and (29.0, ±10.25) mm from the horn axis) as measured from Open Duck Mini v2's
meshes. Before the first structural print: confirm those positions and threads on a real servo,
the horn screw size (M2 vs M2.5 in the Ø2.5 holes on r = 7), that the idler disc exists on the
current revision, and tune the Ø21 bearing bore to the printer (0.15–0.25 mm radial). DR-04 lists
the full set. Open until the bench check.

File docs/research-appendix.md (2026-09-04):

# Research appendix

Condensed findings from the research pass conducted 2026-09-04, before any design work began.
Four parallel research agents plus one follow-up covered: the original MIT Cheetah/Mini Cheetah,
scaled-down open-source QDD quadruped prior art, the Hugging Face duck robot family, and current
legged-RL training stacks. Everything here was verified via live web search / direct repo fetch,
not model memory — items that couldn't be confirmed are marked **unconfirmed** rather than
stated as fact. Treat unconfirmed items as things to re-verify before a purchasing or
architecture decision leans on them.

---

## 1. MIT Cheetah / Mini Cheetah (the geometry/kinematics reference)

| | Original Cheetah (2013) | Cheetah 3 (2019) | **Mini Cheetah (2019)** |
|---|---|---|---|
| Gear ratio | 5.8:1 custom planetary | 7.67:1 | **6:1 single-stage planetary (confirmed)** |
| DOF | 12 (unconfirmed for this gen specifically) | unconfirmed | **12 total — 3/leg × 4 (confirmed)** |
| Mass | ~32 kg (unconfirmed, single-source) | unconfirmed | **~9 kg / 20 lb (confirmed)** |
| Body dims | ~1m × 23cm × 70cm (unconfirmed) | unconfirmed | **48cm L × 27cm W × 30cm H** |
| Encoder | 13-bit magnetic | unconfirmed | **AMS AS5047 magnetic encoder** |
| Peak torque | ~10 Nm/motor | unconfirmed | **17 Nm peak / 6.9 Nm continuous** |
| Knee drive | Four-bar steel linkage from coaxial hip motor | Chain (single source, unconfirmed) | **Timing belt, 1:1, from hip-stacked actuator** |

**Leg architecture**: each Mini Cheetah leg is a **simple serial chain** — one ab/ad revolute
joint + a serial 2R (hip-pitch, knee-pitch) planar linkage — **not** a parallel/5-bar mechanism.
All three actuators per leg are physically stacked coaxially at the hip; the knee is driven
remotely via a 1:1 timing belt. (The original 2013 Cheetah *did* use a real four-bar parallel
linkage for its knee — this is generation-specific, not a constant Cheetah-family trait.)

**The actuator concept** ("proprioceptive actuator", Seok/Kim/Katz et al.): a high torque-density
motor + a deliberately **low** single-stage planetary reduction (kept low so it stays
backdrivable) + field-oriented current control, so ground-reaction force is inferred from motor
current rather than a force sensor or series-elastic element. This is genuine quasi-direct-drive
(QDD) — the whole reason Mini Cheetah can run, jump, and absorb impacts. Mini Cheetah's
controller is a custom PCB built around an **STM32F446** MCU running FOC, communicating over
**CAN** (also UART).

**Open-source status**: the control *software* stack (`mit-biomimetics/Cheetah-Software`, MIT
license) is open, but contains no actuator CAD/BOM/firmware. The actuator itself **is** open
source, via Ben Katz's own repos: `bgkatz/motorcontrol` (FOC firmware), `bgkatz/3phase_integrated`
(controller PCB — EAGLE + Gerbers), `bgkatz/mc-psu-v3` (power supply board) — all MIT licensed.
Katz's MIT **SM thesis** (not PhD — correcting a common mix-up), *"Low Cost, High Performance
Actuators for Dynamic Robots"* (2018), is the primary written source; his build blog covers the
earlier "HobbyKing Cheetah" DIY predecessor. A commercial derivative exists: CubeMars/T-Motor
**AK-series** actuators (e.g. AK80-6) package essentially the same 6:1/AS5047-class recipe as a
product, with an official MIT licensing relationship **unconfirmed**.

**Why this matters for us**: we adopted the 12-DOF serial-leg topology (ab/ad + hip + knee ×4)
as our kinematic reference, but *not* the QDD actuator technology — see decision log in
`docs/HANDOFF.md`.

---

## 2. Scaled-down open-source QDD quadruped prior art

Ranked by relevance to "MIT-Cheetah-style geometry + modern actuators + RL training":

### 🥇 ODRI Solo8 / Solo12 — strongest overall reference
Org: [open-dynamic-robot-initiative](https://github.com/open-dynamic-robot-initiative)
(LAAS-CNRS / Max Planck Institute / NYU / Naver Labs).

- **Actuator** (fully documented, from-scratch QDD build recipe): T-Motor **Antigravity 4004
  300kV** outrunner + **Broadcom AEDT-9810-Z00** optical encoder + dual-stage timing-belt
  reduction (3:1 × 3:1 = **9:1 total**, Conti Synchroflex AT3 belts), 2.5 Nm @ 12A, 150g/module.
- **DOF**: Solo8 = 8 DOF (hip + knee only, no ab/ad); **Solo12 = 12 DOF** (adds ab/ad) — 2.5 kg
  total mass, 3D-printed legs.
- **Electronics**: central **Master Board v2 is ESP32-based** (not STM32), talks to up to 8
  motor-driver boards over **SPI**. The per-motor driver boards are TI-based: the original
  µDriver v2 uses a **TMS320F28069 C2000 DSP + dual DRV8305** gate drivers; the newer
  `open-motor-driver-initiative` board uses a newer C2000 part (TMS320F2838x) that supports
  CAN-FD.
- **License**: BSD-3-Clause (`solo`, `open_robot_actuator_hardware`), BSD-2-Clause
  (`master-board`) — all confirmed directly from each repo's LICENSE file.
- **RL**: real training code exists and is released — [Gepetto/soloRL](https://github.com/Gepetto/soloRL),
  companion to *"Controlling the Solo12 Quadruped Robot with Deep RL"* (Nature Sci. Reports 2023,
  arXiv 2309.16683). Uses **RaiSim** (not Isaac Gym — an earlier synthesis pass surfaced an
  Isaac-Gym/RTX-4090/Raspberry-Pi-5 claim that could not be verified and appears to be a
  hallucinated mixup; disregard it). Real-robot policy code lives in a companion GitLab repo,
  reported 10μs on-robot inference. Published, real sim-to-real result.

### 🥈 Stanford Pupper v3 — strongest secondary reference (system integration)
Code: [Nate711/pupperv3-monorepo](https://github.com/Nate711/pupperv3-monorepo); docs:
[HandsOnRobotics/pupper-v3-documentation](https://github.com/HandsOnRobotics/pupper-v3-documentation)
(docs site blocked from our sandbox — re-verify directly before relying on it).

- **Actuators**: 12× **Steadywin GIM4305** — an integrated, buy-not-build QDD module (4005 BLDC +
  10:1 planetary + AS5047 14-bit encoder + onboard CAN driver), 24V, ~1 Nm continuous / ~3.5 Nm
  stall, 400W class.
- **Compute**: Raspberry Pi 5 + Hailo AI accelerator + Luxonis depth camera; ROS2 workspace with
  a `neural_controller` package. Claims "RL locomotion out of the box" — **whether full RL
  *training* code (vs. just on-robot inference) is public is unconfirmed.**
- **License**: **GPL-3.0** (confirmed) — copyleft, unlike Pupper v1/Doggo's MIT. Cost ~$1000 BOM.

### Stanford Doggo — kinematics reference only
[Nate711/StanfordDoggoProject](https://github.com/Nate711/StanfordDoggoProject). T-Motor MN5212
gimbal motors (2/leg, coaxial) + AS5047P encoders + ODrive v3.5 + Teensy 3.5. Genuine **5-bar/SCARA
parallel linkage**, 2 DOF/leg (8 total) — the best-documented small QDD leg-linkage math found in
this survey. Fusion 360 CAD, MIT license. Open-loop sinusoidal gaits only, no RL. End-of-life;
Stanford points people to Pupper v3 now.

### Stanford Pupper v1 — superseded
[stanfordroboticsclub/StanfordQuadruped](https://github.com/stanfordroboticsclub/StanfordQuadruped).
12× JX Servo CLS6336HV hobby PWM servos (not QDD), Raspberry Pi, MIT license, ~$600-1000,
end-of-life.

### MangDang Mini Pupper — ROS2/vision reference only
[mangdangroboticsclub](https://github.com/mangdangroboticsclub). Proprietary 12.5g custom PWM
servo (not QDD) via PCA9685, Raspberry Pi 4/CM4 (+ ESP32 co-processor on v2), full ROS1/ROS2 +
Nav2 + YOLO11 stack. Apache-2.0 (current repo) / MIT (legacy repo). No RL training code found
anywhere in the org. ~$550-800 kit.

### Other references (brief)
**OpenQuadruped/"Rex"** ([adham-elarabawy/open-quadruped](https://github.com/adham-elarabawy/open-quadruped),
MIT) — 12-DOF hobby-servo quadruped with a genuinely custom single PCB (Gerbers included) and a
published 3-DOF IK derivation; RL was only a TODO, never implemented. Standalone QDD actuator
reference designs (not full quadrupeds) worth knowing about for future custom-actuator work:
**OpenTorque**, **SpryDrive**, **OpenQDD**, **NOMAD BLDC**.

---

## 3. Hugging Face duck robots — two distinct projects

**Important**: "the Hugging Face mini duck project" is actually two related but distinct things.

### Open Duck Mini v2 — open-hardware DIY project (our actual hardware reference)
Created by **Antoine Pirrone** (`apirrone`, Pollen Robotics R&D engineer, Rhoban RoboCup team
member), sponsored (funded/promoted) by Hugging Face and Pollen Robotics — a community project,
not an official HF-authored repo.

- **Repos** (all vendored — see `vendor/README.md`): hardware/BOM
  ([Open_Duck_Mini](https://github.com/apirrone/Open_Duck_Mini), **Apache-2.0**), runtime
  ([Open_Duck_Mini_Runtime](https://github.com/apirrone/Open_Duck_Mini_Runtime), **no license**),
  RL training ([Open_Duck_Playground](https://github.com/apirrone/Open_Duck_Playground), **no
  license**), reference motion
  ([Open_Duck_reference_motion_generator](https://github.com/apirrone/Open_Duck_reference_motion_generator),
  **no license**).
- **Actuators**: 14× **Feetech STS3215** serial-bus smart servos, 7.4V, ~19 kg·cm stall,
  daisy-chained on a TTL serial bus. Two 5-DOF legs + 4-DOF neck/head, plus small 9g hobby servos
  for expressive parts (exact count/use not fully itemized in sources reviewed).
- **Control board / compute**: **Raspberry Pi Zero 2 W** (Runtime repo also supports Pi 5), 64-bit
  Pi OS Lite. Servos driven via a commercial **Waveshare "Bus Servo Adapter (A)"** breakout — UART
  RX/TX to Pi GPIO. **No dedicated custom PCB in the main repo.**
- **Power**: 2× 18650 Li-ion, **2S pack + 2S BMS** (~7.4V nominal — matches servo voltage
  directly), separate **5V UBEC** for the Pi/logic, XT30 connector, USB-C charge module.
- **Sensors**: single **Bosch BNO055** 9-DOF IMU, Raspberry Pi Camera Module, per-foot contact
  switches, **Adafruit MAX98357 I2S** amp + speaker for expression sounds.
- **Training**: **MuJoCo** via `Open_Duck_Playground`, built on/inspired by DeepMind's
  `mujoco_playground` (JAX/Brax-based PPO). Reference motion is **procedurally generated** (not
  motion-captured) using the **Placo** IK library, with imitation-reward design credited as
  inspired by Disney Research's BDX droid work.
- **Released models**: pretrained ONNX walk policies (`BEST_WALK_ONNX*.onnx`) ship directly in the
  hardware repo.
- **Cost**: BOM ≈ €347–414 (~$375–450), under the project's own "$400" target. Build is
  nontrivial (soldering, servo ID/calibration, RPi setup) — described anecdotally as multiple
  days of work.

### Microduck — commercial product (not directly reusable as a hardware base)
Hugging Face acquired Pollen Robotics in **April 2025**; Microduck (Aug 27 2026, $399 assembled)
is their second post-acquisition product (after Reachy Mini). Same creative lineage as Open Duck
Mini, **different hardware, not published as open hardware**.

- **Repos**: firmware/"brain" in Rust ([pollen-robotics/microduck](https://github.com/pollen-robotics/microduck),
  Apache-2.0), RL training ([pollen-robotics/microduck_rl](https://github.com/pollen-robotics/microduck_rl),
  **Apache-2.0 code, but 3D model/asset files are CC BY-SA-NC — non-commercial**). No hardware
  CAD/BOM/PCB published — confirmed by the existence of a community "reverse-engineering" repo
  ([fanhao375/microduck-replica](https://github.com/fanhao375/microduck-replica)) built
  specifically because official files don't exist.
- **Actuators**: "15 motors" per press coverage; exact make/model **not officially published**
  and **unconfirmed** (community analysis argues STS3215 is physically too large for Microduck's
  800g/25cm form factor, implying a different/smaller/custom servo).
- **Compute**: **Rockchip RK3566 SoC + AI accelerator**, 1GB RAM, 32GB storage — confirmed from
  the `microduck` repo README. Rust daemon architecture (`robotd`, `mediad`, `tofd`, `configd`,
  `btd`, `padd`, `updaterd`) over Unix-socket JSON-RPC.
- **Power**: removable NP-F550-style camera battery, ~1hr runtime. Internal regulation
  unconfirmed.
- **Sensors**: **two IMUs**, wide-angle front camera (WebRTC), **8×8 ToF array**, mic + speaker, 2
  NFC antennas.
- **Training**: a **different** stack from Open Duck Mini v2 — **mjlab** (Isaac-Lab-style API over
  GPU-accelerated MuJoCo Warp) + **rsl_rl** (PyTorch PPO), with extensive domain randomization
  (battery sag, command latency, friction, ±1° per-joint backlash) via Rhoban's **BAM**. ~1–2
  hours training on one CUDA GPU at 4096 parallel envs. Onboard inference at 50Hz, ONNX export.
- **Released models**: [huggingface.co/pollen-robotics/microduck-policies](https://huggingface.co/pollen-robotics/microduck-policies)
  (Apache-2.0 ONNX policies: walk/sit/stand/kick/grab/roller-skate/self-recovery) and a browser
  sim sandbox at [huggingface.co/spaces/pollen-robotics/microduck-simulator](https://huggingface.co/spaces/pollen-robotics/microduck-simulator).

**Practical takeaway**: we build on Open Duck Mini v2's *open hardware* (servos, power topology,
sensor choices) while adopting Microduck's *newer training approach* (BAM-based actuator
identification; mjlab as a possible upgrade path once real GPU training is underway).

---

## 4. Legged-robot RL training stacks (2025–2026 survey)

| Stack | Physics engine | HW acceleration | Learning curve | Notable users | Relevance here |
|---|---|---|---|---|---|
| **MuJoCo Playground** | MuJoCo via MJX (JAX) | Any JAX-capable GPU, even CPU-runnable | Low — `pip install playground` | Google DeepMind, Berkeley Humanoid, Unitree Go1/G1, Open Duck Mini | **High** — lightest hardware bar, same lineage Open Duck Mini itself uses |
| **Isaac Lab** | Isaac Sim/PhysX, adding Newton/MJWarp backends | Massively parallel NVIDIA GPU (RTX 4080-class officially, RTX 4060 8GB reported working for lighter loads) | Steep — Omniverse/USD, Docker-heavy | Boston Dynamics Spot, Unitree, ANYbotics | Medium — powerful, heavier install than needed here |
| **Genesis** | Custom multi-physics | Single high-end GPU, very fast (claims up to 43M FPS on RTX 4090) | Low-medium, rough edges | Early-stage adopters | Low-Medium — thin real-hardware sim-to-real track record, open stability bugs as of Aug 2026 |
| **legged_gym + rsl_rl** | Isaac Gym Preview (deprecated) | NVIDIA GPU | Medium | ANYmal (origin), `unitree_rl_gym` | The env scaffolding (`legged_gym`) is legacy; **`rsl_rl` the PPO library is still the de facto standard**, integrated into Isaac Lab, Genesis forks, mjlab |
| **Brax / MJX** | MJX = JAX reimplementation of MuJoCo core | GPU/TPU via JAX | N/A (substrate) | Underlies MuJoCo Playground | Physics layer, not a standalone framework |
| **mjlab** (new, early 2026) | MuJoCo Warp (MJWarp) — NVIDIA-Warp-accelerated, co-built by DeepMind/NVIDIA/Disney Research ("Newton" project) | Requires NVIDIA GPU | Isaac-Lab-style ergonomic API | `unitree_rl_mjlab`, **Pollen Robotics' `microduck_rl`** | **This is what Microduck itself actually uses now** — closest "same stack" match if we have GPU access |

**Sim-to-real for cheap small robots**: DeepMind's **Barkour** paper is the gold-standard
methodology reference (specialist RL skills distilled into a generalist transformer) though the
hardware isn't open. **Solo12**'s published result found only *simple* domain randomization
needed for zero-shot transfer, attributed to its low-inertia, high-bandwidth QDD actuators
narrowing the sim gap — this doesn't directly apply to our smart-servo choice, where
**backlash/friction modeling matters more** (which is exactly what BAM addresses). **Berkeley
Humanoid Lite** is another sub-$5k open reference. Standard control pattern across all of these:
PD position-target per joint, policy at 50Hz, faster low-level tracking loop underneath.

**What's reusable across engine choice, regardless of which one we land on**: the BAM
actuator-identification workflow, domain-randomization code structure, ONNX export + on-robot
inference runtime pattern, PPO policy architecture (small MLP, indifferent to leg count beyond
I/O dimensions), and generic reward-shaping utilities. **What must be rebuilt regardless**:
MJCF/URDF geometry, action-space size/order (12-DOF quadruped vs. the duck's bipedal layout),
gait reference motion (quadruped trot ≠ bipedal walk), per-robot reward terms, and
domain-randomization *ranges* (a fresh BAM identification pass on our actual robot, even reusing
their STS3215 baseline as a starting point).

---

## 5. Side research: "NVIDIA AI Router" (low-priority, informational only)

Checked because the user asked whether it could ease Mac → cloud-GPU access for training. The
real product is **NVIDIA PAIR (Personal AI Router)**, announced **2026-09-03** (literally the day
before this research) at IFA — open source, [NVIDIA/Personal-AI-Router](https://github.com/NVIDIA/Personal-AI-Router).

**It doesn't help with our use case.** PAIR pools multiple machines on your **local/home network**
for **inference** requests (Ollama/LM-Studio-compatible endpoints) — it explicitly does not pool
GPU memory or reach cloud GPUs, and it's inference-only, not training. A Mac can be a participant
*node* in your own house, not a client reaching remote NVIDIA GPUs. For actually offloading
training to the cloud, the more relevant (and **not deeply verified today** — flagged for the
low-priority follow-up task) NVIDIA offering would be **DGX Cloud / DGX Cloud Lepton**, a GPU
marketplace — a distinct, older product line unrelated to PAIR.

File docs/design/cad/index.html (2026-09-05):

Cheetah Pup · Phase 2 · CAD detail of the locked design

# Every printed part, every servo, in the frames the simulator uses

The build123d model of , exported as STEP and STL, with each body's mass, centre of mass and inertia now feeding the MuJoCo model. Orbit the assembly, replay the recorded open-loop gaits on the real geometry, or sweep the joints to check clearances. The tables below are the numbers the simulator reads; the last section is what to confirm on hardware before printing.

SheetDR-04 · CAD detail

Date—

Total mass—

Printed—

Commit—

Unitsmm · g · g·cm²

Show

Pause Speed View

Layers Tub Lid Glass lid Servos Electronics Legs —

PLA parts STS3215 servos TPU feet Battery Pi 5 PCB + IMU

drag · orbit wheel · zoom shift-drag · pan

Frame

Abad 0° Hip -45° Knee 93° All four legs follow the sliders; the trunk stays at the stance height, so the feet leave the ground — this mode is for clearances, not balance.

## Printed parts

## Bodies as the simulator sees them

Centre of mass in each body's own frame (the joint at the origin); principal moments about that centre. Each servo is 55 g spread over its case; electronics are uniform boxes; wiring is 60 g in the trunk.

## Dimensions and interfaces

### Geometry

### Servo mounting convention

Fixed part

3 mm plate on the servo's top-face step

Case screws

4 × M2, Ø2.4 clearance at (8.3, ±10.25) and (29.0, ±10.25)

Bearing

Ø20 horn disc in a Ø21 bore, 0.95 mm proud of the plate

Moving part

4 × Ø2.5 on r = 7 + Ø3.2 centre, on the horn disc

Idler pocket

Ø20 × 2.1 disc on the case bottom, 0.4 mm clearance

Servo

—

### Electronics bay

Battery

70 × 40 × 22 on the floor, rails 44 apart

Pi 5

85 × 56 transverse, standoffs (±24.5, ±29), 3 mm over the battery

PCB + IMU

40 × 60 × 8 under the lid at x = 49, bosses (49 ± 15, ±25)

Lid screws

M2 at (±31, 0) and (0, ±45.5)

Materials

—

## Confirm on hardware before printing

Regenerate: python -m cad.assembly (STEP, STL, mass properties, viewer meshes) → python -m cheetah_pup.mjcf sim/cheetah_pup.xml and --rl → python -m cheetah_pup.validate → python -m cheetah_pup.build_cad_review. Parts are modelled in their MuJoCo body frames, so the STL files drop into the model without transforms.

Gait playback is the open-loop MuJoCo recording (inverse-kinematics targets, no balance feedback) between 3 and 5 s, shown in place. See DR-02 for the full runs and the torque/speed traces.

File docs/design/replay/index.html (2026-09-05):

Cheetah Pup · Phase 1–2 · MuJoCo validation of the locked design

# The locked robot, standing and trotting in simulation

Recorded MuJoCo runs of : the servos track inverse-kinematics gait targets at 50 Hz with no learned policy. Open-loop sends the targets blind; leveled adds one geometric term that lengthens legs under a low corner of the body. Neither balances — a robot that survives both has slack for the RL policy to use. Drag the timeline or hover the charts; the playback and the cursors move together.

SheetDR-02 · sim playback

Model—

Date—

Scale1.5 px : 1 mm

Physics—

Servo—

Control

Gait

Pause Speed Time

## This run

### Side elevation · recorded pose, left side toward viewer

recorded jointscommanded joints (near legs)foot in contact

### Trunk height

### Trunk pitch & roll

pitch (nose down +)roll (left up +)

### LF servo torque

hipkneedashed: 60 % peak allowance · red: 1.91 N·m clamp

### LF joint speed

hipkneered: 5.29 rad/s firmware cap

### LF knee · commanded vs recorded

commandedrecorded

### Foot contact vs commanded stance

commanded stancefoot touching

## All runs

Data table for this run (every 0.5 s)

What was simulated. Each run stands for 1 s on the keyframe pose, then plays 6 s of gait targets from the design library's inverse kinematics. Feet are 10 mm spheres with friction 1.0 on a flat floor; a fall is a trunk below half the stance height or more than 46° of pitch or roll.

How to read it. Open-loop speed below the command is feet slipping and the trunk pitching under the rear legs' push — the front feet float most of the cycle (gait diagram). The leveled run shows how much one cheap correction recovers; the RL policy closes the rest. Torque saturating at the clamp during swing is the stiff firmware loop hitting its limit for a few samples, not a design margin problem — the standing knee torque of matches the 0.22 N·m quasi-static estimate.

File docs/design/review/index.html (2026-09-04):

Cheetah Pup · Phase 1 · leg architecture & proportions

# Three ways to hang twelve servos on a Mini Cheetah skeleton

Same kinematics in every candidate — abduction, hip pitch, knee pitch on each of four legs, serial 2R leg, knees back — sized to the Feetech STS3215 (7.4 V) and to a body that holds a Raspberry Pi 5, a 2S 18650 pack, and the custom bus/power PCB. Pick an architecture, nudge the proportions, watch it move, then record the decision at the bottom.

SheetDR-01 · candidates

RevA

Date—

Scale1.5 px : 1 mm, all views

DrawnClaude · Fable 5.1

Reviewdudgeon

## Candidate

Adirect knee Bbelt knee Cpushrod knee

## Size

S×0.85 Mbaseline L×1.15

Presets set the sliders below; any slider move makes it a custom variant (recorded with your feedback).

## Proportions

## Gait parameters

Trot at these settings is the sizing case for torque and speed.

Pause Speed Phase

### Side elevation · left side toward viewer

### Front elevation

### Joint state · this frame

Leg | Abad ° | Hip ° | Knee ° | Foot x mm | Foot z mm | Phase

Angles follow the Mini Cheetah convention: hip 0° is straight down, negative swings the thigh back; positive knee flexes the shank forward, so the knee sits behind the hip–foot line. Abad positive is abduction. Foot x/z are relative to the hip axis.

STS3215 servoPi 52S 18650 + BMScustom PCBIMUsupport polygonCoM

### Plan · electronics bay & support polygon

## Mass & envelope

## Proportions vs Mini Cheetah

Ratio | This | Mini Cheetah

Mini Cheetah: thigh 209 / shank 195 / abad 62 mm, hips 380 mm apart, stands at 290 mm hip height (hip −46°, knee 92°). Our abad ratio runs high because a 36 mm-long servo sits where their 62 mm actuator did at 2.3× the scale.

## Servo loads · STS3215

## Decision

Records the candidate, the current slider values, and the computed metrics. Claude reads this back to lock the design and generate the sim model.

Choose AChoose BChoose C

shorter body longer legs lower stance taller stance narrower more torque margin faster gait revisit 12 V servos

Save decision Copy summary

### Current proposal

How the numbers are made. Quasi-static: a vertical ground reaction at the foot, standing on four legs (¼ weight each, held continuously → allowance 25 % of stall) and a trot peak on two legs (½ weight × 1.5 dynamic factor, swept over the step → allowance 60 % of stall). Hip torque = force × fore-aft foot offset; knee torque = force × horizontal knee-to-foot offset; abad torque = force × (abad link + 10 mm lateral shift). Speeds come from inverse kinematics along the gait cycle, compared with the servo firmware's 5.29 rad/s target-rate cap (Rhoban BAM identification). Mass is a component model: 12 × 55 g servos, measured electronics, and a parametric estimate of printed parts.

Servo geometry measured from the STS3215 case meshes in Open Duck Mini v2 (45.2 × 24.7 × 35.7 mm, shaft 9.6 mm from the end). Belt ratios use GT2 tooth counts; the pushrod ratio is an average — the real 4-bar varies about ±20 % over the knee range.

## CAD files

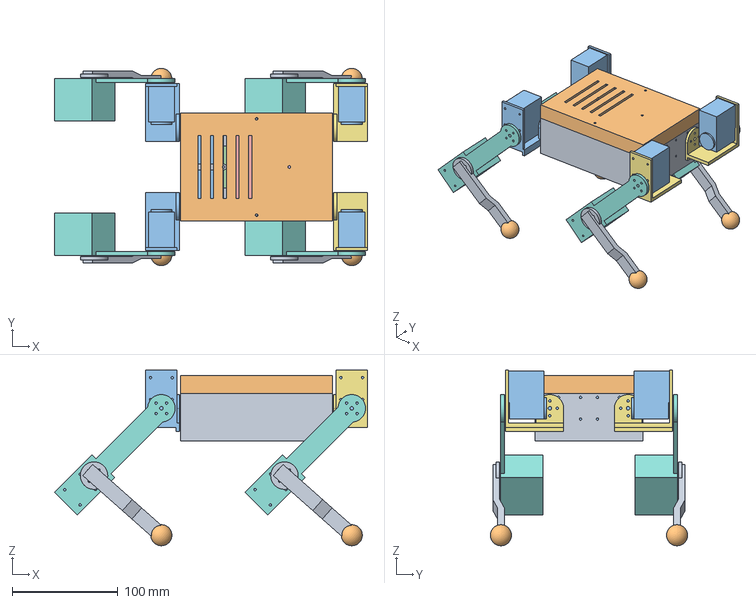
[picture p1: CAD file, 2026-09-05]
cad/exports/step/assembly_nominal_stance.step
295.9 x 186.4 x 166.0 mm

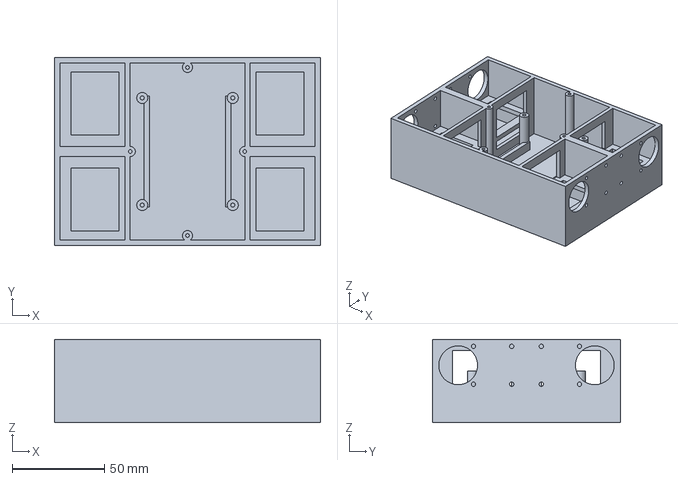
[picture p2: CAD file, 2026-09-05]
cad/exports/step/trunk_tub.step
144.0 x 102.0 x 45.0 mm

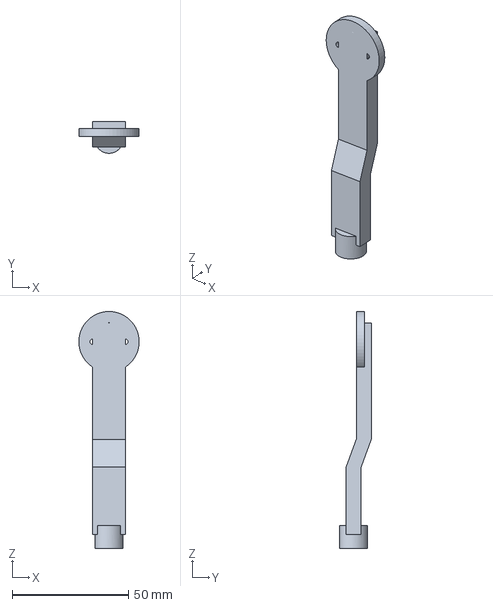
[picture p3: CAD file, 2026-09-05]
cad/exports/step/LH_shank.step
26.0 x 13.7 x 102.0 mm

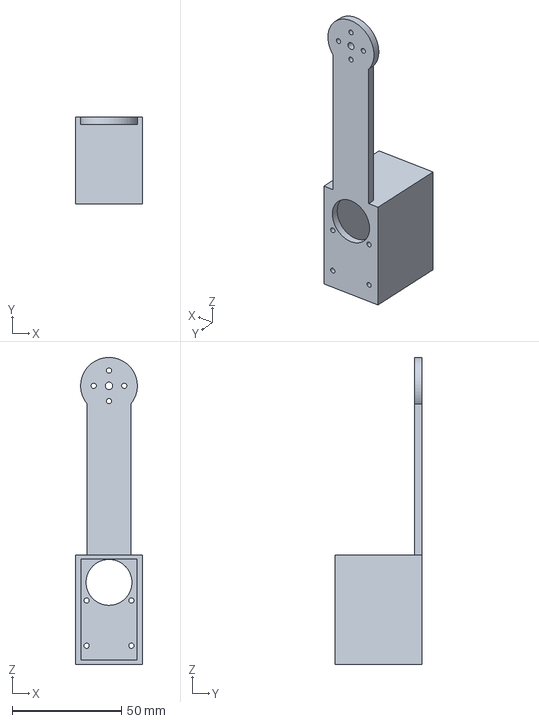
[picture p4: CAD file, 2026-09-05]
cad/exports/step/LF_thigh.step
30.5 x 39.8 x 140.6 mm

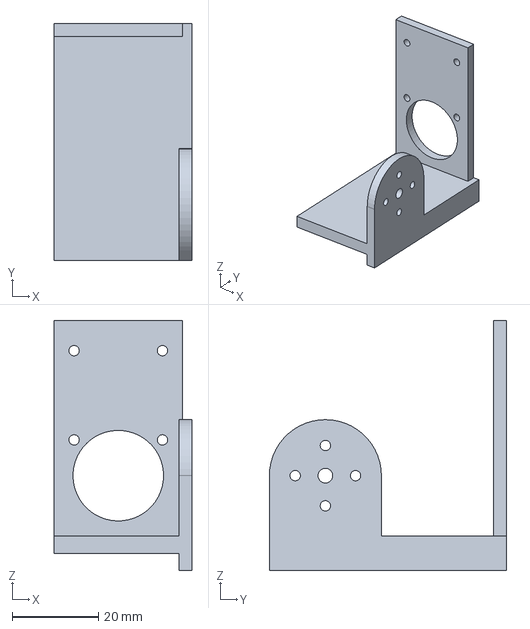
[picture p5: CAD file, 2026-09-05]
cad/exports/step/LH_bracket.step
31.9 x 55.0 x 58.0 mm

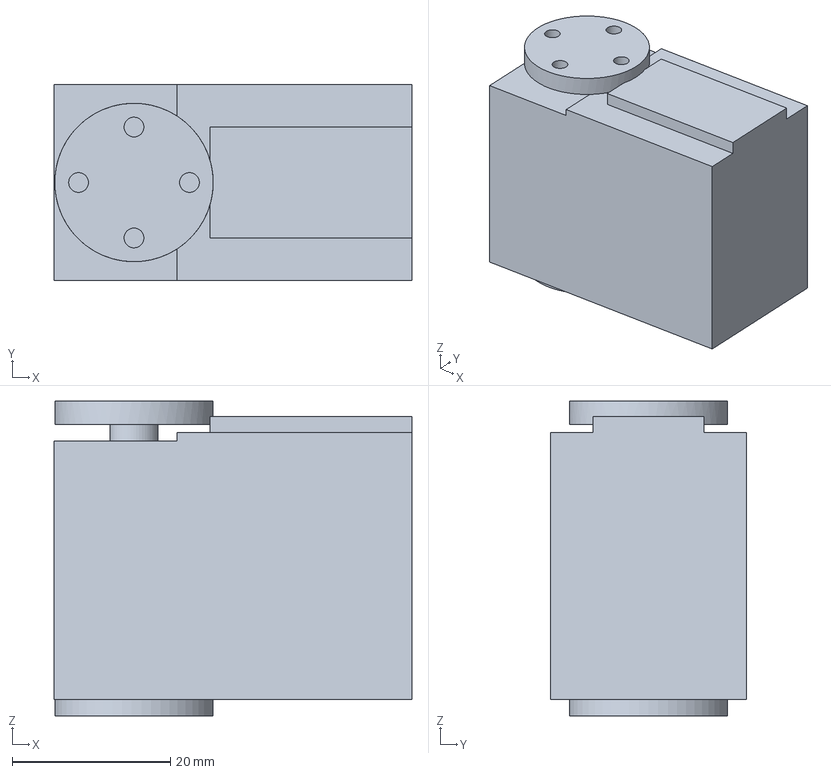
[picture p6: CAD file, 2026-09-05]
cad/exports/step/servo_sts3215.step
45.2 x 24.7 x 39.8 mm

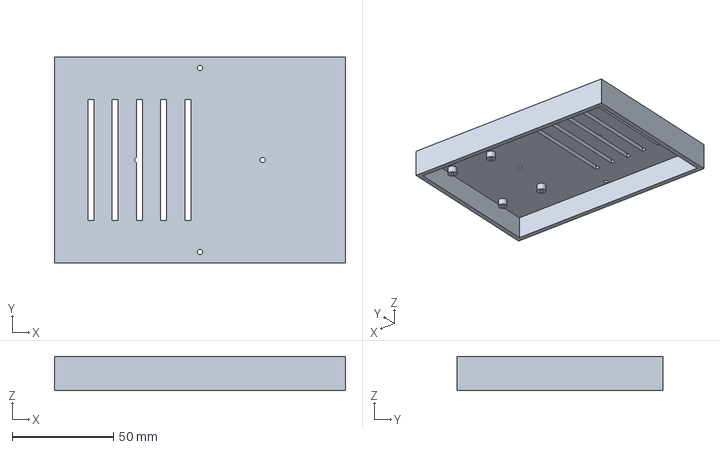
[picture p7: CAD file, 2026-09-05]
cad/exports/step/trunk_lid.step
144.0 x 102.0 x 17.0 mm

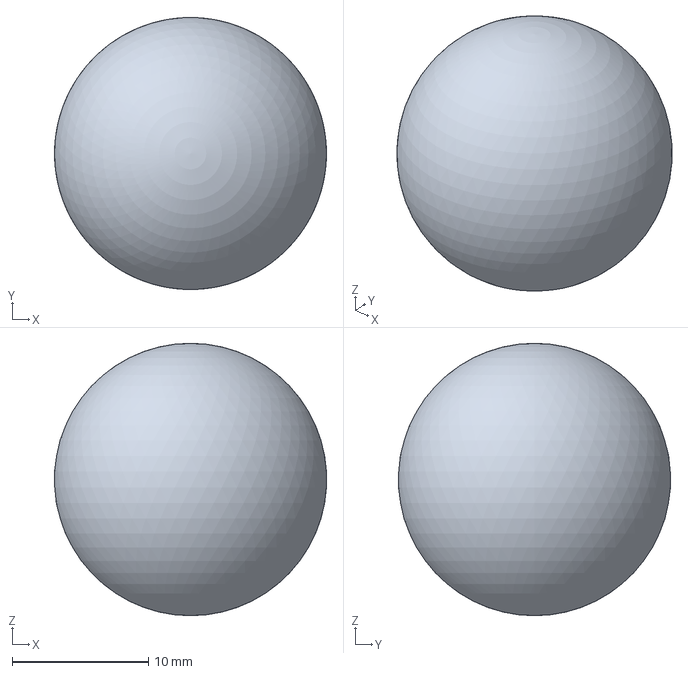
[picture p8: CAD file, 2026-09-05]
cad/exports/step/LH_foot.step
20.0 x 20.0 x 20.0 mm

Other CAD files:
cad/exports/step/RH_thigh.step
cad/exports/step/RH_bracket.step
cad/exports/step/RF_bracket.step
cad/exports/step/RF_thigh.step
cad/exports/step/RF_shank.step
cad/exports/step/LF_foot.step
cad/exports/step/RH_foot.step
cad/exports/step/LF_bracket.step
cad/exports/step/RF_foot.step
cad/exports/step/RH_shank.step
cad/exports/stl/LF_bracket.stl
cad/exports/stl/LF_foot.stl
cad/exports/stl/LF_shank.stl
cad/exports/stl/LF_thigh.stl
cad/exports/stl/LH_bracket.stl
cad/exports/stl/LH_foot.stl
cad/exports/stl/LH_shank.stl
cad/exports/stl/LH_thigh.stl
cad/exports/stl/RF_bracket.stl
cad/exports/stl/RF_foot.stl
cad/exports/stl/RF_shank.stl
cad/exports/stl/RF_thigh.stl
cad/exports/stl/RH_bracket.stl
cad/exports/stl/RH_foot.stl
cad/exports/stl/RH_shank.stl
cad/exports/stl/RH_thigh.stl
cad/exports/stl/servo_sts3215.stl
cad/exports/stl/trunk_lid.stl
cad/exports/stl/trunk_tub.stl

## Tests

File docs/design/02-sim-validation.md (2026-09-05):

# DR-02 — MuJoCo validation of the locked design

**Status**: complete for Phase 1's purpose (viability). Playback page:
https://claude.ai/code/artifact/2db54b1d-2707-4034-895f-95bec2b86281
Source: `docs/design/replay/template.html`, built by `python -m cheetah_pup.build_replay`.
Recordings: `sim/validation/` from `python -m cheetah_pup.validate sim/cheetah_pup.xml`.
Model: `sim/cheetah_pup.xml` from `python -m cheetah_pup.mjcf` (locked design A · M).

## What was tested

| | Result |
|---|---|
| Stand (1 s, hold the keyframe) | 0.8 mm sag, 0.75° droop; knee hold torque **0.244 N·m** (quasi-static estimate 0.22) |
| Open-loop walk, 6 s | stayed up; 0.07 m at 0.012 m/s (commanded 0.062); pitch ≤ 10°, roll ≤ 11° |
| Open-loop trot, 6 s | stayed up; **0.33 m at 0.056 m/s** (commanded 0.168); pitch ≤ 8.5°, roll ≤ 11° |
| Leveled trot (gain 0.7), 6 s | stayed up; 0.62 m at 0.103 m/s; pitch ≤ 18.5°, roll ≤ 19° |
| Peak servo torque in gait | hip and knee touch the 1.91 N·m clamp for 1–4 % of samples during swing; abad ≤ 0.68 N·m |
| Peak joint speed in gait | knee 4.3 rad/s open-loop trot (cap 5.29) |

"Open-loop" = inverse-kinematics joint targets from `cheetah_pup/gait.py` at 50 Hz, no feedback.
"Leveled" = the same plus one geometric term shifting each foot's height by
0.7 × (hip x · sin pitch − hip y · sin roll). Neither balances.

## What it means

1. **The locked geometry is viable on STS3215 servos.** The robot stands with a 10 % duty-cycle
   knee load and survives 6 s of walking and trotting with no controller at all.
2. **Speed loss is posture, not servo capability.** Servo tracking is 2–3° mean error; the front
   feet float ~80 % of the trot cycle because the trunk pitches under the rear legs' push (contact
   duty 21/18/36/40 % vs 50 % commanded). A crude leveling term doubles the speed but oscillates —
   a proportional correction through a laggy position loop has no damping. Balance is the policy's
   job; the hand-written gait is a viability probe, not a controller.
3. **Torque clamp hits are brief and expected**: the firmware loop (kp ≈ 18.8 N·m/rad) saturates
   at ~6° of tracking error during swing reversals. Keep the clamp and BAM's target-rate limit in
   the training model so the policy learns the real robot's limits.

## Model fidelity notes (for the RL environment)

- Primitives with component masses (1.409 kg); no meshes yet. Replace with CAD-derived mass
  properties in Phase 2.
- Servo: PD from BAM's electrical model, clamped at the datasheet stall. Upgrade to BAM's stateful
  MuJoCo actuator (rate-limited target, extended friction) for training.
- Feet: 10 mm spheres, friction 1.0. Contact sensing via MuJoCo touch sensors.
- Sensors present for the observation space: IMU quaternion, gyro, accelerometer; four foot touch
  sensors; joint positions and velocities from the state.

## 2026-09-05 — re-run on the CAD-derived model

Same protocol on `sim/cheetah_pup.xml` regenerated from the Phase 2 CAD (explicit per-body
inertias, 1.391 kg, feet 3.25 mm outboard): stand sag 0.9 mm, droop 0.76°, knee hold 0.249 N·m;
open-loop walk 0.145 m in 6 s (0.024 m/s, pitch ≤ 10.2°), open-loop trot 0.411 m (0.069 m/s,
pitch ≤ 8.7°); leveled trot 0.098 m/s with 21° pitch excursions. No falls. The DR-02 page shows
these runs. Trot is 23 % faster than on the primitive model, mostly from the lower trunk inertia
about pitch (1.55 vs the primitive box's value) — the qualitative picture (front feet floating,
speed loss open-loop) is unchanged and remains the RL policy's job (§9.9).

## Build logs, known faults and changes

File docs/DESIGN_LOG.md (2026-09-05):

# Design log

Dated record of decisions, milestones, and findings. Newest first. The decision table in
`docs/HANDOFF.md` §3 is the summary; this log keeps the reasoning and the state at the time.

## 2026-09-05 — Phase 2 CAD first pass; the sim now runs on CAD mass properties (DR-04)

- **Owner's ask (in chat, away from the computer)**: another round of refinement of the 3D
  model to the next level of detail, then use it in the simulation.
- **CAD** (`cad/`, build123d 0.11): STS3215 modelled from Open Duck Mini v2's case meshes
  (`cad/servo.py`: case, step, gear bump, Ø20 horn disc, idler disc, top-face M2 pattern, horn
  pattern), a servo-frame helper so every servo is placed by where its gear end and horn point;
  parts built in their MuJoCo body frames (`cad/parts.py`): trunk tub and lid, abad bracket,
  thigh with the knee-servo cradle, shank, TPU foot; assembly, STEP/STL export, and per-body
  mass properties (`cad/assembly.py`). Interface convention: 3 mm plate on the servo top-face
  step with 4 × M2, Ø21 bore around the horn disc as a plain bearing, moving part on the horn's
  r = 7 pattern.
- **Packaging refinements found while modelling** (kinematics unchanged): abad link 43 mm,
  abad axes 74 mm apart, hip x-offset 18 mm, feet 3.25 mm outboard of the knee plane; battery on
  the floor with the Pi 5 above it in the centre bay, PCB + IMU hung from the lid over the front
  abad servos; shell 144 × 102 × 62. `cheetah_pup/design.py`'s locked preset and
  `docs/design/locked.json` carry the new values; packaging checks pass.
- **Masses**: printed parts 451 g; robot 1.391 kg (tub 169 g, lid 73 g, brackets 13.6 g, thighs
  24.5 g, shanks 9.3 g, feet 5 g) — 1.6 % under the 1.413 kg parametric estimate. The tub came
  out heavier than the parametric shell (143 g) even after windowing the shelves and ribs.
- **Sim**: `cheetah_pup/mjcf.py` gained a CAD mode (default for the locked design): explicit
  `<inertial>` per body, STL meshes as visuals, servo meshes placed from the recorded frames,
  feet at ±3.25 mm; collisions stay primitive. `sim/cheetah_pup.xml` and the RL variant were
  regenerated; the RL env loads by path so the mesh directory resolves. Re-validation on the CAD
  model: stand sag 0.9 mm, droop 0.76°, knee hold 0.249 N·m; open-loop walk 0.024 m/s and trot
  0.069 m/s over 6 s without falling; leveled trot 0.098 m/s. RL env CPU tests pass (4/4);
  27 fast tests pass, including CAD-vs-MJCF inertia checks.
- **Review**: DR-04 https://claude.ai/code/artifact/6b9c8170-cae2-4a28-a494-7ba0548bcc4b (WebGL viewer of the
  assembly with gait playback from the recordings and a joint sweep for clearances, part and
  body tables, hardware checklist);
  `docs/design/04-cad-detail.md`. DR-02 republished with the CAD masses.
- **Open (§9.10)**: servo hole pattern, horn screw size, idler disc, and bore fit to confirm on a
  real servo; foot socket, wire clips, fork supports not yet modelled; hip pitch limited to about
  ±60° by the knee-servo case at the tub corner.

## 2026-09-04 — RL environment built (DR-03, Fable 5.1)

- **Stack decision for Phase 1**: MuJoCo Playground (MJX, JAX backend on CPU here; `--impl warp`
  for GPU) + Brax PPO — the lineage Open Duck Mini trained on, installable in this sandbox. mjlab
  remains the alternative for Phase 5 if Warp on the cloud GPU is preferred.
- **Environment** (`cheetah_pup/rl/`): joystick velocity-tracking task modeled on Playground's
  Go1 env (same 12-DOF layout), with the real robot's sensor set only in the policy observation,
  servo slew limit on motor targets, rewards rescaled for ~1 N·m torques and ~0.15 m/s speeds,
  domain randomization including servo gain and torque-limit spread. Details in
  `docs/design/03-rl-environment.md`.
- **Model variant** `sim/cheetah_pup_rl.xml`: feet-only collisions, IMU frame sensors, foot
  contact sensors (work under the MJX JAX backend), `home` keyframe.
- **Verified on CPU**: 4 env tests pass (obs 49 / privileged 121, finite reset/step, slew limit,
  fall termination). PPO smoke run: 8 envs, 5,120 steps in 133 s (JIT-dominated), all reward
  terms finite, episodes run full length, checkpoint saved. Brax 0.14.2 needed a shim for the
  `jax.device_put_replicated` call JAX 0.10 removed (`cheetah_pup/rl/compat.py`).
- **Licensing note**: Open Duck Playground's env files carry Apache-2.0 headers even though the
  repo lacks a LICENSE file; ours is written against mujoco_playground's own Apache-2.0 code.

## 2026-09-04 — Design locked (A · M) and first MuJoCo validation (Fable 5.1)

- **Decision (owner, in chat)**: "All of the defaults look fine" on the DR-01 page → candidate
  **A · direct drive, size M, knees back**, baseline proportions (thigh 90 / shank 85 / abad link
  40 mm, hips 180 apart, abad axes 70 apart, shell 148 × 62 mm, hip height 120 mm) and gait
  defaults (60 mm step, 1.4 Hz, 25 mm swing). Recorded as `cheetah_pup.design.locked()` and
  `docs/design/locked.json`; every downstream artifact derives from it.
- **Sim model**: `cheetah_pup/mjcf.py` generates `sim/cheetah_pup.xml` — primitives with the
  component masses (1.409 kg total, matching the sizing), joint conventions verified against the
  kinematics library by test, STS3215 as a MuJoCo `general` actuator with kp 18.8 N·m/rad and
  back-EMF damping 0.56 N·m·s/rad from BAM's model, clamped at the datasheet stall (1.91 N·m);
  reflected inertia 0.026 kg·m² and Coulomb friction 0.05 N·m on the joints; 50 Hz control,
  2 ms physics.
- **Validation (open-loop IK targets, no balance feedback)** — `cheetah_pup/validate.py`,
  `sim/validation/`: stands with 0.8 mm sag and 0.75° droop, knee hold torque 0.244 N·m vs
  0.22 N·m quasi-static; walks 6 s without falling (0.10 m, pitch ≤ 10°); trots 6 s without
  falling (0.37 m, 0.062 m/s vs 0.168 commanded, pitch ≤ 8.5°, roll ≤ 10°). Servo torque
  saturates briefly at hip and knee during swing (stiff position loop hitting its 1.91 N·m clamp),
  which is what costs the commanded speed; peak joint speeds 3.4–5.1 rad/s, at the firmware cap.
  Conclusion: the locked geometry is viable on these servos; an RL policy has slack to work with.
- **Bug fixed on the way**: a `<general>` actuator needs `biastype="affine"` or MuJoCo drops the
  position/velocity terms and applies a constant feed-forward torque — the model collapsed at max
  torque until that was set. Keyframe trunk height now includes the foot radius.
- **DR-02 playback page** published: https://claude.ai/code/artifact/2db54b1d-2707-4034-895f-95bec2b86281
  (`docs/design/replay/`, built by `cheetah_pup.build_replay` from `sim/validation/`).
- **Why open-loop is slow**: servo tracking is good (mean error 2–3°, torque clamp hit only 1–4 %
  of samples); the front feet are simply off the ground ~80 % of the trot cycle because the trunk
  pitches under the rear legs' push. A 6 mm stance depth did nothing; a geometric leveling term
  (foot height ∝ hip x · pitch) swept from gain 0.2 to 1.0 buys speed (0.10 m/s at 0.7) at the cost
  of 18–27° attitude swings — proportional leveling through a laggy position loop oscillates. Kept
  gain 0.7 as the comparison run in DR-02. Conclusion for Phase 5: balance is the policy's job; the
  hand-written gait is only a viability probe.

## 2026-09-04 — Phase 1 candidates published (Fable 5.1)

- **Milestone**: DR-01 review page published with three leg-architecture candidates at true scale,
  animated gaits, live sizing, and decision capture. `docs/design/01-candidates.md` has the
  analysis; `cheetah_pup/` is the canonical design library (16 tests passing).
- **Servo geometry** taken from Open Duck Mini v2's STS3215 case meshes (45.22 × 24.72 × 35.7 mm,
  shaft 9.6 mm from the end, Ø20 drive horn, rear idler disc) and BAM's identified 7.4 V model
  (kt 1.18 N·m/A, R 2.48 Ω, armature 0.026 kg·m², velocity cap 5.29 rad/s, ~1 ms delay).
- **Findings**: servo speed cap is the binding gait constraint (trot ≤ ~1.5 Hz); direct-drive knee
  peaks at 40 % of stall in a trot, so no reduction is required; belt ratio limited to ≤ 1.25:1;
  Pi 5 mounts transversely; hip axis needs ≥ 16 mm clearance beyond the shell end; coaxial hip
  clusters add 70 mm of width.
- **Recommendation**: A (direct drive) — best stack reuse and speed margin; B if the owner wants the
  Mini Cheetah hip cluster and accepts the width and belt modeling.
- **Toolchain confirmed** in this sandbox: build123d 0.11.1 (CAD, Phase 2) and MuJoCo 3.12 (Phase 1
  sim) both install and run; Node 22 and headless Chromium available for page snapshots.
- **Open**: the owner's candidate/size selection (gate for the MJCF milestone).

## 2026-09-04 — Research, interview, and architecture decisions (Sonnet 5)

- Research on MIT Cheetah, scaled open-source QDD quadrupeds, the Hugging Face duck family, and
  legged-RL stacks (`docs/research-appendix.md`).
- Decisions from the owner interview recorded in `docs/HANDOFF.md` §3: STS3215-class smart servos
  over QDD; full 12-DOF Mini Cheetah topology; FDM + outsourced PCB assembly; cloud-GPU training from
  a Mac; scriptable CAD (Onshape unreachable from the sandbox); validate kinematics in sim before
  real CAD; $600–1,500 budget; likely open-source release (MIT license on this repo).
- Seven reference repos vendored under `vendor/` with license notes.

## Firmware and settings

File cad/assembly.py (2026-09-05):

"""Assemble the robot at the nominal stance, export STEP/STL, and compute per-body mass properties.

    python -m cad.assembly            # writes cad/exports/{step,stl,mass_properties.json,viewer_meshes.json}

`mass_properties.json` also carries the servo and electronics placements the MJCF generator needs;
`viewer_meshes.json` holds the unique part meshes, their instances per body, and the kinematic tree
for the DR-04 review page's viewer.

Mass properties are computed per MuJoCo body from the printed parts (volume × material density ×
infill factor), the servos (measured 55 g spread over the case solid), and the electronics (measured
masses as uniform boxes), all in the body's own frame — exactly what `<inertial>` needs.
"""

from __future__ import annotations

import json
import math
import pathlib
import time

import numpy as np
from build123d import Box, CenterOf, Compound, Location, Pos, Rot, Shape, export_step, export_stl

from . import params as C
from . import parts as PT
from . import servo as SV

OUT = pathlib.Path(__file__).resolve().parent / "exports"
LEGS = [("LF", 1, True), ("RF", -1, True), ("LH", 1, False), ("RH", -1, False)]
WIRING_MASS = 0.060


def rigid(shape: Shape, mass: float) -> dict:
    """Mass, centre of mass (m), and inertia about the CoM (kg·m²) of a shape carrying `mass`."""
    v = shape.volume
    c = shape.center(CenterOf.MASS)
    I = np.array(shape.matrix_of_inertia, dtype=float) * (mass / v) * 1e-6
    return {"mass": mass, "com": np.array([c.X, c.Y, c.Z]) / 1000.0, "inertia": I, "volume_mm3": v}


def combine(items: list[dict]) -> dict:
    """Combine rigid bodies given in one frame: total mass, CoM, inertia about the total CoM."""
    M = sum(it["mass"] for it in items)
    com = sum(it["mass"] * it["com"] for it in items) / M
    I = np.zeros((3, 3))
    for it in items:
        d = it["com"] - com
        I += it["inertia"] + it["mass"] * (np.dot(d, d) * np.eye(3) - np.outer(d, d))
    return {"mass": M, "com": com, "inertia": I}


def fullinertia(I: np.ndarray) -> list:
    return [float(I[0, 0]), float(I[1, 1]), float(I[2, 2]), float(I[0, 1]), float(I[0, 2]), float(I[1, 2])]


def rotmat_to_quat(R: np.ndarray) -> list[float]:
    """Unit quaternion (w, x, y, z) of a rotation matrix (Shepperd's method)."""
    tr = R[0, 0] + R[1, 1] + R[2, 2]
    if tr > 0:
        s = math.sqrt(tr + 1.0) * 2
        q = [0.25 * s, (R[2, 1] - R[1, 2]) / s, (R[0, 2] - R[2, 0]) / s, (R[1, 0] - R[0, 1]) / s]
    elif R[0, 0] > R[1, 1] and R[0, 0] > R[2, 2]:
        s = math.sqrt(1.0 + R[0, 0] - R[1, 1] - R[2, 2]) * 2
        q = [(R[2, 1] - R[1, 2]) / s, 0.25 * s, (R[0, 1] + R[1, 0]) / s, (R[0, 2] + R[2, 0]) / s]
    elif R[1, 1] > R[2, 2]:
        s = math.sqrt(1.0 + R[1, 1] - R[0, 0] - R[2, 2]) * 2
        q = [(R[0, 2] - R[2, 0]) / s, (R[0, 1] + R[1, 0]) / s, 0.25 * s, (R[1, 2] + R[2, 1]) / s]
    else:
        s = math.sqrt(1.0 + R[2, 2] - R[0, 0] - R[1, 1]) * 2
        q = [(R[1, 0] - R[0, 1]) / s, (R[0, 2] + R[2, 0]) / s, (R[1, 2] + R[2, 1]) / s, 0.25 * s]
    return [float(v) for v in q]


def servo_placement(frame: SV.ServoFrame, body: str) -> dict:
    """Where the servo mesh (exported in its own L, W, A frame) sits in a MuJoCo body: pos (m), quat."""
    R = np.array([frame.l_dir, frame.w_dir, frame.a_dir], dtype=float).T   # columns = frame axes
    return {"body": body, "pos": [round(v / 1000.0, 6) for v in frame.origin], "quat": [round(v, 6) for v in rotmat_to_quat(R)]}


def printed(shape: Shape, cls: str, density: float = C.PLA_DENSITY) -> tuple[dict, float]:
    mass = shape.volume * 1e-9 * density * C.INFILL[cls]
    return rigid(shape, mass), mass


def body_location(leg: str, side: int, front: bool, which: str) -> Location:
    """World location of a body frame at the nominal stance (trunk at z = stance + foot radius)."""
    z0 = C.STANCE + C.FOOT_R
    hx = (1 if front else -1) * C.HIP_TO_HIP / 2
    loc = Pos(0, 0, z0)
    if which == "trunk":
        return loc
    loc = loc * Pos(hx, side * C.ABAD_Y, 0)
    if which == "abad":
        return loc
    loc = loc * Pos(0, side * C.ABAD_LINK, 0) * Rot(0, -math.degrees(C.Q_HIP), 0)
    if which == "hip":
        return loc
    return loc * Pos(0, 0, -C.THIGH) * Rot(0, -math.degrees(C.Q_KNEE), 0)


def tessellate(shape: Shape, tol=0.3, ang=0.4):
    verts, tris = shape.tessellate(tol, ang)
    return [[round(v.X, 2), round(v.Y, 2), round(v.Z, 2)] for v in verts], [list(t) for t in tris]


def build(export: bool = True, viewer: bool = True) -> dict:
    t0 = time.time()
    (OUT / "step").mkdir(parents=True, exist_ok=True)
    (OUT / "stl").mkdir(parents=True, exist_ok=True)
    parts: dict[str, dict] = {}       # printed parts: name -> {shape, cls, body, side...}
    bodies: dict[str, list] = {}      # body -> list of rigid items
    servos: dict[str, dict] = {}      # servo mesh placements per body, for the MJCF
    world: list[tuple[str, str, Shape, str]] = []   # (name, kind, shape in world, body)
    mesh_shapes: dict[str, Shape] = {}              # unique shapes for the viewer, by mesh key
    instances: list[dict] = []                      # viewer instances: mesh key placed in a body (mm)

    def shared(key: str, make):
        if key not in mesh_shapes:
            mesh_shapes[key] = make()
        return mesh_shapes[key]

    def instance(name, kind, body, mesh, pos=(0.0, 0.0, 0.0), quat=(1.0, 0.0, 0.0, 0.0)):
        instances.append({"name": name, "kind": kind, "body": body, "mesh": mesh,
                          "pos": [round(float(v), 4) for v in pos], "quat": [round(float(v), 6) for v in quat]})

    def add_part(name, shape, cls, body, density=C.PLA_DENSITY):
        props, mass = printed(shape, cls, density)
        parts[name] = {"shape": shape, "cls": cls, "body": body, "mass": mass, "props": props}
        bodies.setdefault(body, []).append(props)

    def add_rigid(name, shape, mass, body):
        bodies.setdefault(body, []).append(rigid(shape, mass))
        return shape

    # ---- trunk
    tub, lid = shared("trunk_tub", PT.trunk_tub), shared("trunk_lid", PT.trunk_lid)
    add_part("trunk_tub", tub, "shell", "trunk")
    add_part("trunk_lid", lid, "shell", "trunk")
    instance("trunk_tub", "print", "trunk", "trunk_tub")
    instance("trunk_lid", "print", "trunk", "trunk_lid")
    servo_solid = shared("servo", SV.servo_solid)
    rigid_trunk = []
    for leg, side, front in LEGS:
        fr = PT.abad_servo_frame(side, front)
        s = SV.placed(servo_solid, fr)
        add_rigid(f"{leg}_abad_servo", s, SV.MASS, "trunk")
        servos[f"{leg}_abad_servo"] = servo_placement(fr, "trunk")
        instance(f"{leg}_abad_servo", "servo", "trunk", "servo", fr.origin, servos[f"{leg}_abad_servo"]["quat"])
        rigid_trunk.append((f"{leg}_abad_servo", "servo", s))
    battery = Pos(*C.BATTERY_C) * shared("battery", lambda: Box(*C.BATTERY))
    pi = Pos(*C.PI_C) * shared("pi5", lambda: Box(*C.PI))
    pcb = Pos(*C.PCB_C) * shared("pcb", lambda: Box(*C.PCB_ENV))
    wiring = Pos(0, 0, 0) * Box(100, 60, 10)
    from cheetah_pup.electronics import PI5, BATTERY_2S, PCB, IMU
    add_rigid("battery", battery, BATTERY_2S.mass, "trunk")
    add_rigid("pi5", pi, PI5.mass, "trunk")
    add_rigid("pcb", pcb, PCB.mass + IMU.mass, "trunk")
    add_rigid("wiring", wiring, WIRING_MASS, "trunk")
    instance("battery", "battery", "trunk", "battery", C.BATTERY_C)
    instance("pi5", "pi", "trunk", "pi5", C.PI_C)
    instance("pcb", "pcb", "trunk", "pcb", C.PCB_C)
    rigid_trunk += [("battery", "battery", battery), ("pi5", "pi", pi), ("pcb", "pcb", pcb)]

    # ---- legs
    leg_shapes = {}
    for leg, side, front in LEGS:
        sd = "L" if side > 0 else "R"
        br = shared(f"bracket_{sd}{'F' if front else 'H'}", lambda: PT.abad_bracket(side, front))
        add_part(f"{leg}_bracket", br, "plate", f"{leg}_abad")
        instance(f"{leg}_bracket", "print", f"{leg}_abad", f"bracket_{sd}{'F' if front else 'H'}")
        hf = PT.hip_servo_frame(side)
        hip_servo = SV.placed(servo_solid, hf)
        add_rigid(f"{leg}_hip_servo", hip_servo, SV.MASS, f"{leg}_abad")
        servos[f"{leg}_hip_servo"] = servo_placement(hf, f"{leg}_abad")
        instance(f"{leg}_hip_servo", "servo", f"{leg}_abad", "servo", hf.origin, servos[f"{leg}_hip_servo"]["quat"])
        th = shared(f"thigh_{sd}", lambda: PT.thigh(side))
        add_part(f"{leg}_thigh", th, "plate", f"{leg}_hip")
        instance(f"{leg}_thigh", "print", f"{leg}_hip", f"thigh_{sd}")
        kf = PT.knee_servo_frame(side)
        knee_servo = SV.placed(servo_solid, kf)
        add_rigid(f"{leg}_knee_servo", knee_servo, SV.MASS, f"{leg}_hip")
        servos[f"{leg}_knee_servo"] = servo_placement(kf, f"{leg}_hip")
        instance(f"{leg}_knee_servo", "servo", f"{leg}_hip", "servo", kf.origin, servos[f"{leg}_knee_servo"]["quat"])
        sh = shared(f"shank_{sd}", lambda: PT.shank(side))
        add_part(f"{leg}_shank", sh, "beam", f"{leg}_knee")
        instance(f"{leg}_shank", "print", f"{leg}_knee", f"shank_{sd}")
        ft = shared(f"foot_{sd}", lambda: PT.foot(side))
        add_part(f"{leg}_foot", ft, "tpu", f"{leg}_knee", C.TPU_DENSITY)
        instance(f"{leg}_foot", "foot", f"{leg}_knee", f"foot_{sd}")
        leg_shapes[leg] = {"abad": [(f"{leg}_bracket", "print", br), (f"{leg}_hip_servo", "servo", hip_servo)],
                           "hip": [(f"{leg}_thigh", "print", th), (f"{leg}_knee_servo", "servo", knee_servo)],
                           "knee": [(f"{leg}_shank", "print", sh), (f"{leg}_foot", "foot", ft)]}

    # ---- world placement at the nominal stance
    L = body_location("", 1, True, "trunk")
    world += [("trunk_tub", "print", L * tub, "trunk"), ("trunk_lid", "print", L * lid, "trunk")]
    world += [(n, k, L * s, "trunk") for (n, k, s) in rigid_trunk]
    for leg, side, front in LEGS:
        for which in ("abad", "hip", "knee"):
            Lb = body_location(leg, side, front, which)
            for (n, k, s) in leg_shapes[leg][which]:
                world.append((n, k, Lb * s, f"{leg}_{which}"))

    # ---- mass properties
    report = {"generated": time.strftime("%Y-%m-%d"), "design": C.P.name, "units": "kg, m, kg·m² (inertia about the body CoM, body frame)",
              "infill": C.INFILL, "densities": {"pla": C.PLA_DENSITY, "tpu": C.TPU_DENSITY}, "parts": {}, "bodies": {}}
    for name, p in parts.items():
        pr = p["props"]
        report["parts"][name] = {"body": p["body"], "class": p["cls"], "volume_cm3": round(pr["volume_mm3"] / 1000, 2),
                                 "mass_g": round(p["mass"] * 1000, 1), "com_m": [round(float(v), 5) for v in pr["com"]]}
    total = 0.0
    for body, items in bodies.items():
        cb = combine(items)
        total += cb["mass"]
        report["bodies"][body] = {"mass": round(float(cb["mass"]), 5), "com": [round(float(v), 5) for v in cb["com"]],
                                  "fullinertia": [float(f"{v:.4e}") for v in fullinertia(cb["inertia"])]}
    report["total_mass"] = round(total, 4)
    printed_total = sum(p["mass"] for p in parts.values())
    report["printed_mass"] = round(printed_total, 4)
    # placements the MJCF generator needs besides the printed parts (which are in their body frames)
    report["servos"] = servos
    report["servo_mesh"] = "servo_sts3215.stl"
    report["electronics"] = {
        "battery": {"body": "trunk", "pos": [v / 1000.0 for v in C.BATTERY_C], "size": [v / 1000.0 for v in C.BATTERY]},
        "pi5": {"body": "trunk", "pos": [v / 1000.0 for v in C.PI_C], "size": [v / 1000.0 for v in C.PI]},
        "pcb": {"body": "trunk", "pos": [v / 1000.0 for v in C.PCB_C], "size": [v / 1000.0 for v in C.PCB_ENV]},
    }
    report["stance"] = {"trunk_z": (C.STANCE + C.FOOT_R) / 1000.0, "q_hip": C.Q_HIP, "q_knee": C.Q_KNEE}

    if export:
        for name, p in parts.items():
            export_step(p["shape"], str(OUT / "step" / f"{name}.step"))
            export_stl(p["shape"], str(OUT / "stl" / f"{name}.stl"), tolerance=0.15, angular_tolerance=0.3)
        export_stl(servo_solid, str(OUT / "stl" / report["servo_mesh"]), tolerance=0.15, angular_tolerance=0.3)
        export_step(servo_solid, str(OUT / "step" / "servo_sts3215.step"))
        assembly = Compound(children=[s for (_, _, s, _) in world])
        export_step(assembly, str(OUT / "step" / "assembly_nominal_stance.step"))
        (OUT / "mass_properties.json").write_text(json.dumps(report, indent=1))
    if viewer:
        tree = [{"name": "trunk", "parent": None, "pos": [0.0, 0.0, 0.0], "axis": None}]
        for leg, side, front in LEGS:
            hx = (1 if front else -1) * C.HIP_TO_HIP / 2
            tree += [{"name": f"{leg}_abad", "parent": "trunk", "pos": [hx, side * C.ABAD_Y, 0.0], "axis": [side, 0, 0]},
                     {"name": f"{leg}_hip", "parent": f"{leg}_abad", "pos": [0.0, side * C.ABAD_LINK, 0.0], "axis": [0, -1, 0]},
                     {"name": f"{leg}_knee", "parent": f"{leg}_hip", "pos": [0.0, 0.0, -C.THIGH], "axis": [0, -1, 0]}]
        meshes = {}
        for key, shape in mesh_shapes.items():
            v, t = tessellate(shape)
            meshes[key] = {"v": [c for p in v for c in p], "t": [i for tri in t for i in tri]}
        viewer_data = {"design": C.P.name, "generated": report["generated"], "units": "mm",
                       "stance": report["stance"], "bodies": tree, "meshes": meshes, "instances": instances,
                       "part_mass_g": {n: pp["mass_g"] for n, pp in report["parts"].items()}}
        (OUT / "viewer_meshes.json").write_text(json.dumps(viewer_data, separators=(",", ":")))
    report["seconds"] = round(time.time() - t0, 1)
    return report


def main():
    r = build()
    print(f"{r['design']}: total {r['total_mass']:.3f} kg, printed {r['printed_mass']*1000:.0f} g, {r['seconds']} s")
    for name, p in r["parts"].items():
        print(f"  {name:14s} {p['mass_g']:6.1f} g  ({p['class']}, {p['volume_cm3']} cm³)")
    for body, b in r["bodies"].items():
        print(f"  body {body:9s} {b['mass']*1000:6.1f} g  com {[round(v*1000,1) for v in b['com']]} mm")


if __name__ == "__main__":
    main()

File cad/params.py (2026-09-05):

"""Dimensions (mm) for the CAD, derived from the locked design plus CAD-only constants."""

from __future__ import annotations

from cheetah_pup.design import locked
from cheetah_pup.electronics import PI5, BATTERY_2S, PCB
from cheetah_pup.analysis import nominal_pose
from . import servo as SV

MM = 1000.0
P = locked()

THIGH = P.thigh * MM
SHANK = P.shank * MM
ABAD_LINK = P.abad_link * MM
HIP_TO_HIP = P.hip_to_hip * MM
ABAD_TO_ABAD = P.abad_to_abad * MM
HIP_X_OFFSET = P.hip_x_offset * MM
BODY_H = P.body_height * MM
SHELL_LEN = P.shell_length * MM
SHELL_W = P.shell_width * MM
WALL = P.wall * MM
FOOT_R = P.foot_radius * MM
FOOT_Y = P.foot_y_offset * MM
STANCE = P.stance_height * MM

# Nominal joint angles (rad) of the stance the assembly is exported in
Q_HIP, Q_KNEE = nominal_pose(P, True)

# Printed-part constants
PLATE = 3.0            # bracket plates on servo top faces
THIGH_PLATE = 3.5      # thigh plate: sits on the hip horn disc, carries the knee servo
PAD = 3.5              # shank pad on the knee horn disc
SPLIT_Z = 14.0         # tub/lid split, above the abad servo tops (12.36)
CLEAR = 0.4            # print clearance around servo cases

# Trunk-frame positions
END_WALL_OUTER = SHELL_LEN / 2                      # 72 mm for the locked design
END_WALL_INNER = END_WALL_OUTER - WALL
ABAD_SEAT_X = END_WALL_INNER - SV.STEP_A            # horn-seat plane of the abad servo (front)
ABAD_Y = ABAD_TO_ABAD / 2

# Electronics (trunk frame, mm)
FLOOR_Z = -BODY_H / 2 + WALL
BATTERY = tuple(v * MM for v in BATTERY_2S.size)   # (x, y, z) as mounted: transverse
BATTERY_C = (0.0, 0.0, FLOOR_Z + BATTERY[2] / 2)
PI = (PI5.size[1] * MM, PI5.size[0] * MM, PI5.size[2] * MM)   # transverse: 56 along x, 85 along y
PI_C = (0.0, 0.0, FLOOR_Z + BATTERY[2] + 3.0 + PI[2] / 2)
PI_HOLES = [(x, y) for x in (-24.5, 24.5) for y in (-29.0, 29.0)]
PCB_ENV = (PCB.size[0] * MM, PCB.size[1] * MM, PCB.size[2] * MM)
PCB_C = (END_WALL_INNER - PCB_ENV[0] / 2, 0.0, BODY_H / 2 - WALL - 4.0 - PCB_ENV[2] / 2)
PCB_HOLES = [(PCB_C[0] + dx, dy) for dx in (-15.0, 15.0) for dy in (-25.0, 25.0)]
LID_BOSSES = [(-31.0, 0.0), (31.0, 0.0), (0.0, -45.5), (0.0, 45.5)]

# Materials
PLA_DENSITY = 1240.0   # kg/m^3
TPU_DENSITY = 1200.0
# Effective solid fraction of printed parts (perimeters + infill) by part class
INFILL = {"shell": 0.95, "plate": 0.85, "beam": 0.75, "tpu": 1.0}

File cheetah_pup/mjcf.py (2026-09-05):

"""Generate a MuJoCo MJCF model from a DesignParams.

    python -m cheetah_pup.mjcf sim/cheetah_pup.xml           # locked design: CAD inertias + meshes
    python -m cheetah_pup.mjcf sim/cheetah_pup_rl.xml --rl   # training variant of the same
    python -m cheetah_pup.mjcf out.xml --no-cad              # Phase 1 primitive model (any preset)
    python -m cheetah_pup.mjcf sim/cheetah_pup.xml --bam     # BAM-implied torque limit instead of datasheet

Two levels of fidelity:

* primitive (`cad=False`): the shell, servo cases, and electronics are boxes carrying their component
  masses; thighs and shanks are capsules; feet are spheres. Every mass comes from
  `analysis.structure_masses`, `electronics`, and `servo`, and MuJoCo derives inertia from each geom.
  Works for any candidate/preset, so the sizing studies and the design-review pages use it.
* CAD (`cad=True`, the default whenever `cad/exports/mass_properties.json` matches the design): every
  body carries an explicit `<inertial>` computed by `cad/assembly.py` from the printed parts (volume ×
  density × infill), the servos, and the electronics, and the printed parts and servos are shown as
  the exported STL meshes. Collision geometry stays primitive — foot spheres, plus a shell box and leg
  capsules in the full model (hidden in geom group 3) — which is what the RL environment assumes.

Joint conventions match `kinematics.py`: abad positive = abduction on both sides (axis +x on the
left, -x on the right); hip and knee hinges are about -y so positive angles swing the foot
forward and, for the knee, put the knee behind the hip-foot line.

Actuators are the STS3215's firmware position loop reduced to a MuJoCo `general` actuator:
torque = kp (q_ref - q) - kd q_dot, clamped to the stall torque. kp and the back-EMF damping kd
come from Rhoban BAM's identified electrical model (see `servo.py`); Coulomb friction and the
reflected rotor inertia go on the joint.
"""

from __future__ import annotations

import argparse
import json
import os
import pathlib

from .analysis import structure_masses, nominal_pose
from .design import DesignParams, locked
from .electronics import PI5, BATTERY_2S, PCB, IMU, WIRING_MASS
from .gait import LEGS, LEG_SIDE, LEG_FRONT
from .servo import STS3215

CONTROL_HZ = 50
TIMESTEP = 0.002

JOINT_RANGE = {"abad": (-0.8, 0.8), "hip": (-1.6, 1.6)}
KNEE_RANGE = (0.05, 2.7)

ROOT = pathlib.Path(__file__).resolve().parent.parent
CAD_PROPS = ROOT / "cad" / "exports" / "mass_properties.json"
MESH_DIR = ROOT / "cad" / "exports" / "stl"
PRINTED_PARTS = ["trunk_tub", "trunk_lid"] + [f"{leg}_{part}" for leg in LEGS for part in ("bracket", "thigh", "shank")]
ELECTRONICS_RGBA = {"battery": "0.3 0.42 0.63 0.6", "pi5": "0.3 0.55 0.5 0.6", "pcb": "0.37 0.55 0.23 0.6"}


def servo_gains(torque_limit: str = "datasheet") -> dict:
    """kp [N·m/rad], kd [N·m·s/rad], and torque limit [N·m] from the BAM model."""
    sv = STS3215
    duty_per_rad = 0.166 * 32 * 1.0049          # BAM: error_gain * firmware kp * error_gain_ratio
    torque_per_volt = sv.kt / sv.resistance
    kp = duty_per_rad * sv.vin * torque_per_volt
    kd = sv.kt * sv.kt / sv.resistance          # back-EMF
    limit = sv.stall_torque if torque_limit == "datasheet" else sv.model_stall_torque()
    return {"kp": kp, "kd": kd, "limit": limit, "no_load_speed": sv.max_pwm * sv.vin / sv.kt}


def load_cad(p: DesignParams) -> dict:
    """The CAD mass-properties/placement report for `p`, or a clear error about how to make it."""
    if not CAD_PROPS.exists():
        raise FileNotFoundError(f"{CAD_PROPS} is missing: run `python -m cad.assembly` (needs the `cad` extra)")
    cad = json.loads(CAD_PROPS.read_text())
    if cad["design"] != p.name:
        raise ValueError(f"CAD exports are for {cad['design']!r}, not {p.name!r}: rerun `python -m cad.assembly`")
    return cad


def cad_available(p: DesignParams) -> bool:
    try:
        load_cad(p)
        return True
    except (FileNotFoundError, ValueError):
        return False


def _fmt(vals, nd=5) -> str:
    return " ".join(f"{v:.{nd}f}" for v in vals)


def _box(name, pos, size, mass, cls="visual", extra=""):
    return (f'<geom name="{name}" type="box" class="{cls}" pos="{_fmt(pos)}" size="{_fmt(size)}" '
            f'mass="{mass:.5f}" {extra}/>')


def _inertial(body: dict) -> str:
    return (f'<inertial pos="{_fmt(body["com"], 6)}" mass="{body["mass"]:.5f}" '
            f'fullinertia="{" ".join(f"{v:.4e}" for v in body["fullinertia"])}"/>')


def _servo_mesh(name: str, placement: dict) -> str:
    return (f'<geom name="{name}" type="mesh" mesh="sts3215" class="servo_mesh" '
            f'pos="{_fmt(placement["pos"], 6)}" quat="{_fmt(placement["quat"], 6)}"/>')
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

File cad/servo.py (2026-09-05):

"""Feetech STS3215 as measured from Open Duck Mini v2's case meshes (see docs/design/04-cad-detail.md).

Servo frame (millimetres): origin on the shaft axis at the horn-seat plane (the case's top face
around the horn); L = case length axis (+L toward the gear end, 35.1 mm; the short end is at
-10.1 mm); W = width axis (±12.36); A = shaft axis (+A toward the horn).

Instances are placed with `place(origin, l_dir, a_dir)`, which builds the frame from where the
gear end and the horn should point.
"""

from __future__ import annotations

from dataclasses import dataclass

from build123d import Box, Cylinder, Location, Plane, Pos, Rot, Vector, Shape

CASE_L = (-10.1, 35.1)      # mm along L
CASE_W = 12.36              # half width
CASE_A = (-32.6, 0.0)       # bottom face to horn seat
STEP_L = (5.45, 35.1)       # raised step on the top face, 1.1 mm
STEP_A = 1.1
BUMP_L = (9.6, 35.1)        # gear cover bump, |W| < 7, to 3.1 mm
BUMP_W = 7.0
BUMP_A = 3.1
HORN_HUB_R, HORN_HUB_A = 3.05, (0.0, 2.1)
HORN_DISC_R, HORN_DISC_A = 10.0, (2.1, 5.05)
IDLER_DISC_R, IDLER_DISC_A = 10.0, (-34.7, -32.6)
HORN_HOLE_R, HORN_HOLE_DIA = 7.0, 2.5      # 4 holes on the disc at (±7, 0) and (0, ±7)
HORN_CENTER_DIA = 3.2
MOUNT_HOLES_TOP = [(8.3, 10.25), (8.3, -10.25), (29.0, 10.25), (29.0, -10.25)]   # (L, W), M2 tapped
MOUNT_HOLES_BOTTOM = [(8.3, 10.25), (8.3, -10.25)]
CASE_SCREWS = [(32.7, 10.0), (32.7, -10.0), (-7.1, 9.35), (-7.1, -9.35)]         # through the case
MASS = 0.055                # kg

# Printed-part interface conventions derived from the above
BEARING_BORE_DIA = 21.0     # the Ø20 horn disc rides in this bore of the fixed part
PLATE_A = (STEP_A, STEP_A + 3.0)   # a 3 mm mounting plate sits on the step: A in [1.1, 4.1]
DISC_PROUD = HORN_DISC_A[1] - PLATE_A[1]   # 0.95 mm of disc beyond the plate for the moving part to seat on
M2_CLEARANCE_DIA = 2.4
M2_TAP_DIA = 1.7


@dataclass(frozen=True)
class ServoFrame:
    origin: tuple      # mm, in the host body frame
    l_dir: tuple       # unit vector of +L
    a_dir: tuple       # unit vector of +A (horn direction)

    @property
    def plane(self) -> Plane:
        return Plane(origin=Vector(*self.origin), x_dir=Vector(*self.l_dir), z_dir=Vector(*self.a_dir))

    @property
    def w_dir(self) -> tuple:
        v = Vector(*self.a_dir).cross(Vector(*self.l_dir))
        return (v.X, v.Y, v.Z)

    def to_host(self, l: float, w: float, a: float) -> Vector:
        return Vector(*self.origin) + Vector(*self.l_dir) * l + Vector(*self.w_dir) * w + Vector(*self.a_dir) * a


def _box(l0, l1, w0, w1, a0, a1) -> Shape:
    return Pos((l0 + l1) / 2, (w0 + w1) / 2, (a0 + a1) / 2) * Box(l1 - l0, w1 - w0, a1 - a0)


def _cyl(r, a0, a1, l=0.0, w=0.0) -> Shape:
    return Pos(l, w, (a0 + a1) / 2) * Cylinder(r, a1 - a0)


def servo_solid(with_horn: bool = True, with_idler: bool = True) -> Shape:
    """The servo in its own frame (L, W, A) → (X, Y, Z)."""
    s = _box(CASE_L[0], CASE_L[1], -CASE_W, CASE_W, CASE_A[0], CASE_A[1])
    s = s + _box(STEP_L[0], STEP_L[1], -CASE_W, CASE_W, 0.0, STEP_A)
    s = s + _box(BUMP_L[0], BUMP_L[1], -BUMP_W, BUMP_W, STEP_A, BUMP_A)
    if with_horn:
        s = s + _cyl(HORN_HUB_R, *HORN_HUB_A) + _cyl(HORN_DISC_R, *HORN_DISC_A)
        for (l, w) in [(HORN_HOLE_R, 0), (-HORN_HOLE_R, 0), (0, HORN_HOLE_R), (0, -HORN_HOLE_R)]:
            s = s - _cyl(HORN_HOLE_DIA / 2, HORN_DISC_A[0] - 0.1, HORN_DISC_A[1] + 0.1, l, w)
    if with_idler:
        s = s + _cyl(IDLER_DISC_R, *IDLER_DISC_A)
    return s


def servo_pocket(clearance: float = 0.4, idler: bool = True) -> Shape:
    """Volume to subtract from a part that cradles the case (no horn: the horn lives in the bore)."""
    c = clearance
    s = _box(CASE_L[0] - c, CASE_L[1] + c, -CASE_W - c, CASE_W + c, CASE_A[0] - c, BUMP_A + c)
    if idler:
        s = s + _cyl(IDLER_DISC_R + c, IDLER_DISC_A[0] - c, IDLER_DISC_A[1] + c)
    return s


def horn_pattern_cutter(a0: float, a1: float, center_dia: float = HORN_CENTER_DIA) -> Shape:
    """Holes matching the horn disc: 4 × M2 clearance at r = 7 plus the centre screw, spanning A in [a0, a1]."""
    s = _cyl(center_dia / 2, a0, a1)
    for (l, w) in [(HORN_HOLE_R, 0), (-HORN_HOLE_R, 0), (0, HORN_HOLE_R), (0, -HORN_HOLE_R)]:
        s = s + _cyl(M2_CLEARANCE_DIA / 2, a0, a1, l, w)
    return s


def mount_pattern_cutter(a0: float, a1: float, holes=MOUNT_HOLES_TOP, dia: float = M2_CLEARANCE_DIA) -> Shape:
    """Clearance holes through a plate on the top face, matching the case's tapped M2 holes."""
    s = None
    for (l, w) in holes:
        c = _cyl(dia / 2, a0, a1, l, w)
        s = c if s is None else s + c
    return s


def bearing_bore_cutter(a0: float, a1: float) -> Shape:
    return _cyl(BEARING_BORE_DIA / 2, a0, a1)


def placed(shape: Shape, frame: ServoFrame) -> Shape:
    """Move a shape built in the servo frame into the host body frame."""
    return frame.plane.location * shape

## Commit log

2026-09-04 Initial project scaffolding: research, decisions, and reference repos
    Establishes the pre-design foundation for the Cheetah Pup project: a
    hobbyist-scale quadruped RL robot combining MIT Mini Cheetah's 12-DOF body
    geometry/kinematics with Hugging Face/Pollen Robotics' Open Duck Mini v2
    actuator and stack choices.
    - docs/HANDOFF.md: comprehensive handoff document with decision log,
    architecture, phased build plan, budget, safety, and open questions
    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
2026-09-04 Phase 1: design library and DR-01 leg-architecture candidates
    Adds the cheetah_pup design library (STS3215 geometry measured from Open
    Duck Mini v2 meshes, BAM actuator model, Mini Cheetah-derived presets,
    3-DOF leg kinematics, gait generation, mass/torque/speed/packaging
    sizing) with a 16-test suite, and the DR-01 review page: true-scale
    side/front/plan views of candidates A/B/C with animated gaits, live
    sizing, and decision capture, built from the package data so the page
    and the analysis cannot drift.
    Sizing found the STS3215 speed cap, not torque, to be the binding gait
    constraint (trot ≤ ~1.5 Hz), that direct drive needs no knee reduction
    (40% of stall at trot peak), that the Pi 5 fi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
    [analysis.py, build_artifact.py, design.py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]
2026-09-04 Lock design A·M, generate the MuJoCo model, validate, publish DR-02 playback
    Records the owner's acceptance of the DR-01 defaults (candidate A direct
    drive, size M) as cheetah_pup.design.locked() and docs/design/locked.json.
    Adds cheetah_pup/mjcf.py, which generates sim/cheetah_pup.xml from the
    locked parameters: primitives carrying the component masses (1.409 kg),
    joint conventions verified against the kinematics library by test, and
    STS3215 servos as PD position actuators derived from BAM's electrical
    model, clamped at the datasheet stall.
    cheetah_pup/validate.py settles the stand pose (0.8 mm sag, knee hold
    0.244 N·m vs 0.22 estimated) and plays IK gaits open-loop and with a
    geometric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
    [build_replay.py, design.py, gait.py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]
2026-09-04 RL environment on MuJoCo Playground (MJX) for the locked design
    Adds cheetah_pup/rl: a joystick velocity-tracking task modeled on
    Playground's Go1 environment for the same 12-DOF abad/hip/knee layout,
    with the real robot's sensor set only in the policy observation, motor
    targets slew-limited to the STS3215 firmware cap, rewards rescaled for
    ~1 N·m torques and ~0.15 m/s speeds, domain randomization including servo
    gain and torque-limit spread, and a Brax PPO runner with a CPU smoke mode.
    The model generator gains an --rl variant (feet-only collisions, IMU frame
    sensors, foot contact sensors, home keyframe), verified to step under the
    MJX JAX backend. A compatibility shim restores jax.device_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
    [mjcf.py]
2026-09-05 Phase 2 CAD first pass: build123d model, CAD-derived MuJoCo model, DR-04 review
    - cad/: STS3215 modelled from the measured Open Duck case meshes with a servo-frame
    placement helper; printed parts built in their MuJoCo body frames (trunk tub and lid,
    abad brackets, thighs with the knee-servo cradle, shanks, TPU feet); assembly with
    per-body mass, centre of mass and inertia; STEP/STL exports and viewer meshes
    - Packaging refinements in the locked design, kinematics unchanged: abad link 43 mm,
    abad axes 74 mm apart, hip x-offset 18 mm, feet 3.25 mm outboard, Pi 5 above the
    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
    [LF_bracket.step, LF_bracket.stl, LF_foot.step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]
